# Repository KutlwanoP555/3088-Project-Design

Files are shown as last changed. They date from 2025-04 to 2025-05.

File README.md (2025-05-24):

**** Repository for a power subsystem****

Group 127 
EEE3088F Design principles

# ⚡ Micro-Mouse Power Subsystem

This repository documents the design of a  **Power Subsystem** for the Micro-Mouse (MM) project. The power subsystem is responsible for delivering regulated power to all components of the micro-mouse.
---

## 📋 System Requirements

To meet the course requirements, the power subsystem must achieve the following:

- ✅ **Drive up to 4 motors bidirectionally**, using the assigned pins.
  - 2x brushed DC motors (200 mA each)
  - 2x auxiliary motors (500 mA each)
- ✅ **Integrate an INA219** for battery monitoring via I²C.
  - A0 and A1 pins must not both be tied to GND.
- ✅ **Charge the battery from a 9V input source.**
- ✅ **Support two charging modes**:
  - Low current: 200 mA
  - High current: 600 mA ±100 mA (from the battery's perspective)
- ✅ **Integrate USB-C** and negotiate a **9V supply** from a USB host.
- ✅ **Provide 2x external load switches**:
  - Must support 1 A each, with high-side connection to 5V.
- ✅ **Provide regulated 3.3V and 5V outputs**:
  - 3.3V @ 300 mA max ±5% accuracy
  - 5V @ 1.5 A max ±5% accuracy
- ✅ **Include an ON/OFF switch**:
  - OFF: Leakage current < 30 μA
  - ON: Must handle up to 2 A peak current
  - Must shut down both 5V and 3.3V rails

---

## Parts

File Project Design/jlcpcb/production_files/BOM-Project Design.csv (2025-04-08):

Comment | Designator | Footprint | LCSC | Quantity
4.7uH | L1 | L_6.3x6.3_H3 | C1034 | 1
10uF | C13,C19,C6,C9 | C_1206_3216Metric | C13585 | 4
MCP73812T-420I-OT | U9 | SOT-23-5 | C144308 | 1
DRV8833PWP | U1,U2 | HTSSOP-16-1EP_4.4x5mm_P0.65mm_EP3.4x5mm_Mask2.46x2.31mm_ThermalVias | C1556089 | 2
USB 3.1 C 6PF | USBC1 | USB-C-SMD_TYPE-C-USB-13 | C168701 | 1
0.4R | R6,R7 | R_0603_1608Metric | C171375 | 2
Conn_01x02_Pin |  | JST_PH_S2B-PH-K_1x02_P2.00mm_Horizontal | C173752 | 0
10k | R17 | R_0603_1608Metric | C17414 | 1
47K | R5,R8 | R_0603_1608Metric | C17713 | 2
5R2 | R12,R14 | R_0603_1608Metric | C17724 | 2
1R | R3,R4 | R_0603_1608Metric | C17928 | 2
0.01uF | C1,C4 | C_1206_3216Metric | C1846 | 2
1uF | C10,C11,C12,C16,C17,C20,C23,C24,C25,C3,C8 | C_1206_3216Metric | C1848 | 11
TPS613222ADBV | U8 | SOT-23-3 | C2071163 | 1
NMOS | Q2 | SOT-23-3_L2.9-W1.3-P1.90-LS2.4-BR | C20917 | 1
HUSB237-AA001-DN06R | U10 | TDFN-6_L2.0-W2.0-P0.65-TL-EP | C22373734 | 1
TPS22918TDBVRQ1 | U3,U5,U7 | SOT-23-6_L2.9-W1.6-P0.95-LS2.8-BR | C2653760 | 3
SW_Wuerth_450301014042 | SW3 | SW_Slide-03_Wuerth-WS-SLTV_10x2.5x6.4_P2.54mm | C2887259 | 1
4.7uF | C21,C22 | C_1206_3216Metric | C29823 | 2
2K | Rfastcharge1 | R_0402_1005Metric | C4109 | 1
3K | R_normalcharging1 | R_0603_1608Metric | C4211 | 1
75R | R20 | R_0603_1608Metric | C4275 | 1
1k | R1,R19 | R_1206_3216Metric | C4410 | 2
62R | R11,R13,R16 | R_0603_1608Metric | C4962 | 3
0.001 | R18 | R_0603_1608Metric | C500734 | 1
2.2uF | C2,C5 | C_1206_3216Metric | C50254 | 2
AP2112K-3.3 | U13 | TSOT-23-5 | C51118 | 1
INA219AIDCNR | U11 | SOT-23-8 | C87469 | 1
TestPoint_Small | TP38 | TestPoint_Pad_1.0x1.0mm |  | 1
TestPoint_Small | TP37 | TestPoint_Pad_1.0x1.0mm |  | 1
TestPoint_Small | TP36 | TestPoint_Pad_1.0x1.0mm |  | 1
TestPoint_Small | TP30 | TestPoint_Pad_1.0x1.0mm |  | 1
TestPoint_Small | TP29 | TestPoint_Pad_1.0x1.0mm |  | 1
TestPoint_Small | TP26 | TestPoint_Pad_1.0x1.0mm |  | 1
Conn_02x16_Odd_Even |  | PinHeader_2x16_P2.54mm_Vertical |  | 0

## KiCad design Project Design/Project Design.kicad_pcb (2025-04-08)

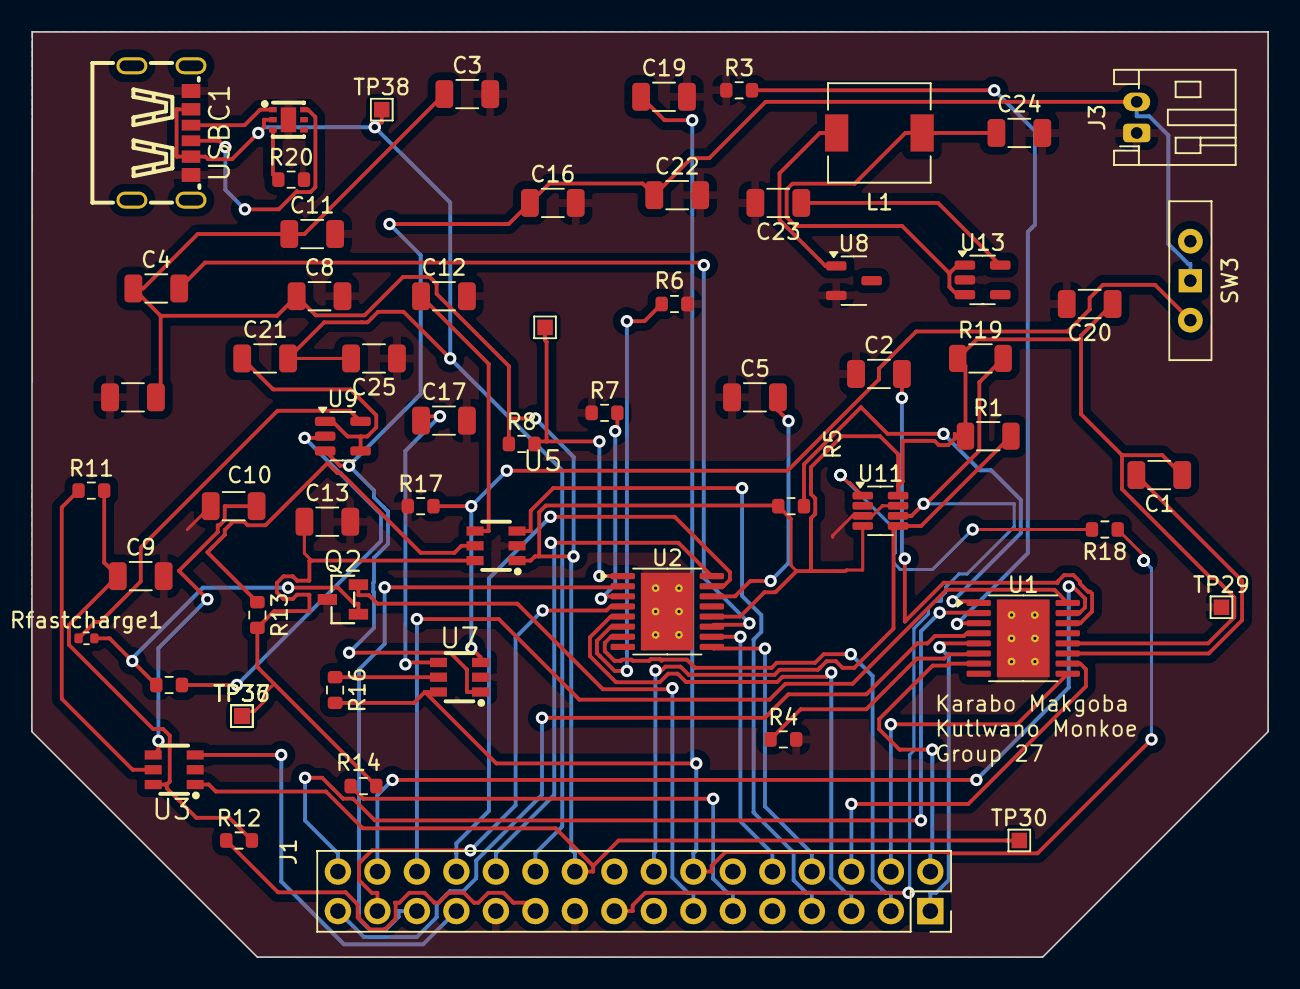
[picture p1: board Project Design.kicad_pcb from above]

Board: 2 copper layers, 79.5 x 59.5 mm, 61 parts (0 on the bottom side), 58 nets.

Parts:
C1, C4: 0.01uF; C_1206_3216Metric
C2, C5: 2.2uF; C_1206_3216Metric
C3, C6, C9, C13, C19: 10uF; C_1206_3216Metric
C8, C10, C11, C12, C16, C17, C23, C24, C25: 1uF; C_1206_3216Metric
C20: 22uF; C_1206_3216Metric
C21, C22: 4.7uF; C_1206_3216Metric
J1: Conn_02x16_Odd_Even; PinHeader_2x16_P2.54mm_Vertical
J3: Conn_01x02_Pin; JST_PH_S2B-PH-K_1x02_P2.00mm_Horizontal
L1: 4.7uH; L_6.3x6.3_H3
Q2: NMOS; SOT-23-3_L2.9-W1.3-P1.90-LS2.4-BR
R1, R19: 1k; R_1206_3216Metric
R3, R4: 1R; R_0603_1608Metric
R5, R8: 47K; R_0603_1608Metric
R6, R7: 0.4R; R_0603_1608Metric
R11, R13, R16: 62R; R_0603_1608Metric
R12, R14: 5R2; R_0603_1608Metric
R17: 10k; R_0603_1608Metric
R18: 0.001; R_0603_1608Metric
R20: 75R; R_0603_1608Metric
R_normalcharging1: 3K; R_0603_1608Metric
Rfastcharge1: 2K; R_0402_1005Metric
SW3: SW_Wuerth_450301014042; SW_Slide-03_Wuerth-WS-SLTV_10x2.5x6.4_P2.54mm
TP26, TP29, TP30, TP36, TP37, TP38: TestPoint_Small; TestPoint_Pad_1.0x1.0mm
U1, U2: DRV8833PWP; HTSSOP-16-1EP_4.4x5mm_P0.65mm_EP3.4x5mm_Mask2.46x2.31mm_The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
U3, U5, U7: TPS22918TDBVRQ1; SOT-23-6_L2.9-W1.6-P0.95-LS2.8-BR
U8: TPS613222ADBV; SOT-23-3
U9: MCP73812T-420I-OT; SOT-23-5
U10: HUSB237-AA001-DN06R; TDFN-6_L2.0-W2.0-P0.65-TL-EP
U11: INA219AIDCNR; SOT-23-8
U13: AP2112K-3.3; TSOT-23-5
USBC1: USB 3.1 C 6PF; USB-C-SMD_TYPE-C-USB-13

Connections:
/5V: C1.1, C3.1, C4.1, C6.2, C8.1, C11.1, C20.1, J1.20, R1.1, R5.1, R8.1, R19.1, TP30.1, U1.12 (VM), U2.12 (VM), U3.1 (VIN), U5.1 (VIN), U11.4 (VS), U11.8 (A1)
/9V: C21.2, C25.2, J1.22, TP38.1, U10.2 (VUSB), USBC1.A9 (VBUS), USBC1.B9 (VBUS)
/Fast charge CTR: J1.13, Q2.2 (G)
/I2C1_SCL: J1.16, R1.2, U11.5 (SCL)
/I2C1_SDA: J1.17, R19.2, U11.6 (SDA)
/Mtr1 C1: J1.28, U1.16 (AIN1)
/Mtr1 C2: J1.30, U1.15 (AIN2)
/Mtr1 O1: J1.32, U1.2 (AOUT1)
/Mtr1 O2: J1.31, U1.4 (AOUT2)
/Mtr2 C1: J1.4, U1.9 (BIN1)
/Mtr2 C2: J1.6, U1.10 (BIN2)
/Mtr2 O1: J1.2, U1.7 (BOUT1)
/Mtr2 O2: J1.1, U1.5 (BOUT2)
/Mtr3 C1: J1.24, U2.16 (AIN1)
/Mtr3 C2: J1.26, U2.15 (AIN2)
/Mtr3 O1: J1.27, U2.2 (AOUT1)
/Mtr3 O2: J1.29, U2.4 (AOUT2)
/Mtr4 C1: J1.8, U2.9 (BIN1)
/Mtr4 C2: J1.10, U2.10 (BIN2)
/Mtr4 O1: J1.3, U2.7 (BOUT1)
/Mtr4 O2: J1.5, U2.5 (BOUT2)
/V+: C19.1, J1.14, R16.2, R18.1, U7.6 (VOUT)
/Vbat+: C16.1, C22.1, J3.2, SW3.1 (B), U7.1 (VIN), U9.3 (V_{BAT})
/Vload: C24.1, L1.1, U13.1 (VIN), U13.3 (EN)
/ex ctrl1: J1.25, U3.3 (ON)
/ex ctrl2: J1.7, U5.3 (ON)
/out1: J1.21, R12.1
/out2: J1.11, R14.1
GND: C2.1, C3.2, C5.1, C6.1, C8.2, C9.2, C10.2, C11.2, C12.2, C13.2, C16.2, C17.2, C19.2, C20.2, C22.2, C23.2, C24.2, C25.1, J1.19, J1.23, J3.1, Q2.3 (S), R3.1, R4.2, R6.2, R7.1, R17.1, R20.2, TP29.1, U1.13 (GND), U1.17 (GND(PPAD)), U2.13 (GND), U2.17 (GND(PPAD)), U3.2 (GND), U5.2 (GND), U7.2 (GND), U8.2 (GND), U10.7 (GND), U11.3 (GND), U11.7 (A0), U13.2 (GND), USBC1.A12 (GND), USBC1.B12 (GND)
unnamed: Q2.1 (D), R_normalcharging1.1, Rfastcharge1.2
unnamed: R17.2, SW3.3 (A), U7.3 (ON)
unnamed: R3.2, U1.3 (AISEN)
unnamed: R4.1, U1.6 (BISEN)
unnamed: C1.2, U1.11 (VCP)
unnamed: C2.2, U1.14 (VINT)
unnamed: R5.2, U1.1 (nSLEEP)
unnamed: R7.2, U2.3 (AISEN)
unnamed: R6.1, U2.6 (BISEN)
unnamed: C4.2, U2.11 (VCP)
unnamed: C5.2, U2.14 (VINT)
unnamed: R8.2, TP26.1, U2.1 (nSLEEP)
unnamed: C10.1, U3.4 (CT)
unnamed: R11.1, U3.5 (QOD)
unnamed: C9.1, R11.2, R12.2, TP36.1, U3.6 (VOUT)
unnamed: C12.1, U5.4 (CT)
unnamed: R13.1, U5.5 (QOD)
unnamed: C13.1, R13.2, R14.2, TP37.1, U5.6 (VOUT)
unnamed: C17.1, U7.4 (CT)
unnamed: R16.1, U7.5 (QOD)
unnamed: L1.2, U8.1 (SW)
unnamed: C21.1, U9.1 (CE), U9.4 (V_{DD})
unnamed: Rfastcharge1.1, U9.5 (PROG)
unnamed: R_normalcharging1.2, U9.2 (V_{SS})
unnamed: U10.1 (CC1), USBC1.A5 (CC1)
unnamed: U10.6 (CC2), USBC1.B5 (CC2)
unnamed: R20.1, U10.3 (VSET)
unnamed: R18.2, U11.1 (IN+)
unnamed: C23.1, U13.5 (VOUT)

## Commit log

2025-03-20 Adding project files to github
    [Project Design.kicad_pcb, Project Design.kicad_sch]
2025-03-23 Updated my part
    [Project Design.kicad_sch]
2025-03-24 Fixed motor set up also added components that we will need for the USB C 9V charging
    [Project Design.kicad_sch]
2025-03-25 Add to the usb section still need to update it, add footprint for the 6P connector. I might opt for a 16P connector which is honestly overkill in my opinion
    [Project Design.kicad_sch]
2025-03-26 Thing are neat
    [Project Design.kicad_sch, freerouting.dsn, temp-freerouting.dsn]
2025-03-26 Putting everything together
    [Project Design.kicad_sch]
2025-03-28 updated part numbers
    [Project Design.kicad_sch]
2025-04-08 Final design, hopefully it works
    [BOM-Project Design.csv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]
